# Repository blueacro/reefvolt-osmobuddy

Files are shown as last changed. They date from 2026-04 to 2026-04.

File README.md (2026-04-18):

# OsmoBuddy

OsmoBuddy is an open-source RO/DI (Reverse Osmosis / Deionization) monitor and controller for reef aquariums. It is built around an ESP32 and [ESPHome](https://esphome.io/), and feeds into [Home Assistant](https://www.home-assistant.io/) for dashboards, automations, and alerting.

For the full design story — including installation photos, parts sources, and discussion with other reefers — see the Reef2Reef thread:

**[osmoBuddy: RO/DI monitor and controller (reef2reef.com)](https://www.reef2reef.com/threads/osmobuddy-ro-di-monitor-and-controller.1078681/)**

## What it does

OsmoBuddy **monitors**:

- **Flow rate** from an inline impeller flow sensor (post-filter in the reference install)
- **Up to three pressures** from 0–5 V pressure transducers. In the reference install:
  - pre-filter (before the sediment / carbon blocks)
  - post-filter (membrane inlet)
  - RO storage tank line pressure
  — the display shows the pressure drop across the filter blocks, so it's obvious when they clog.
- **Up to three switches** (e.g. float switches on a salt-mix / ATO reservoir)

And **controls**:

- **Up to four 24 V valves or relays.** In the reference install these drive:
  - the **main water inlet valve** (a direct-acting non-diaphragm solenoid — this is the one that must not fail, so a reliable valve is used here)
  - a **flush valve** bridged across the flow restrictor to flush the RO membrane
  - (spare) a salt-mix reservoir refill solenoid
- **One on-board dry-contact relay** for signaling other controllers — for example, an **Apex** switch input used to gate automatic water change pumps (e.g. preventing AWC pumps from running after a salt-mix refill until salt has been added manually).

### Control logic

The stock firmware implements automatic pressure-based water production:

1. When storage-tank pressure drops below the **Turn On Pressure** setpoint, both the inlet and flush valves open — a **pre-flush** at startup.
2. After ~30 s the flush valve closes and the membrane starts producing water into the tank.
3. When tank pressure reaches the **Turn Off Pressure** setpoint, the flush valve re-opens for a **post-flush**.
4. After ~30 s the inlet valve closes; the flush valve stays open for a few more seconds to bleed off pressure, then closes.

It also supports a salt-mix auto-fill with a high-float safety cutoff, and a latching dry-contact signal out to an external controller.

> TDS measurement is **not** on this revision — it's planned for a future spin.

## Features

- ESP32-C3 Wi-Fi MCU running ESPHome
- ADS1115 16-bit ADC — 3 channels for 0–5 V pressure transducers
- Pulse-counter flow totalizer with persistent state across reboots
- PCA9554 I/O expander driving solenoid / relay outputs through a high-side driver
- On-board signal relay for dry-contact output to Apex or similar
- 1.3" SH1106 128×64 OLED for live local status (pressures, state, totalizer)
- Rotary encoder with push-button for local UI
- CAN transceiver (TCAN1044) for future expansion
- USB-C for flashing / debug
- 12 V DC input with on-board 5 V and 3.3 V rails

## Reference parts

| Part | Source |
|---|---|
| 24 V flush valve | AliExpress |
| 24 V main inlet valve | McMaster-Carr [5489T413](https://www.mcmaster.com/5489T413/) |
| Pressure transducers | 1/8" NPT, 100 PSI, 0–5 V, stainless — Amazon |
| Flow sensor | Inline impeller type — Amazon |

## Repository layout

| Path | Contents |
|---|---|
| `osmobuddy.yaml` | ESPHome firmware configuration |
| `osmobuddy-schematics.pdf` | Rendered schematic |
| `gerber/osmobuddy_v1/` | Gerber files for PCB fabrication |
| `bom/` | Bill of Materials (CSV) |
| `pnp/` | Pick-and-place files for assembly |
| `3d/` | Enclosure, wall mount, knob, and pump-switch add-on (Inventor, STL, 3MF) |
| `LICENSE` | Apache License 2.0 |

## Firmware

The firmware is a single ESPHome configuration (`osmobuddy.yaml`). To flash:

1. Install [ESPHome](https://esphome.io/).
2. Create a `secrets.yaml` alongside `osmobuddy.yaml` with your Wi-Fi credentials:
   ```yaml
   wifi_ssid: "your-ssid"
   wifi_password: "your-password"
   ```
3. Compile and upload:
   ```bash
   esphome run osmobuddy.yaml
   ```

Once connected, OsmoBuddy appears in Home Assistant via the ESPHome integration and exposes all sensors, switches, and the `Turn On Pressure` / `Turn Off Pressure` / `Force Off` controls.

## Manufacturing

The `gerber/`, `bom/`, and `pnp/` directories contain what's needed to order assembled boards from JLCPCB, PCBWay, or similar. The enclosure in `3d/` is designed for FDM 3D printing.

## License

Licensed under the Apache License, Version 2.0. See [LICENSE](LICENSE) for details.

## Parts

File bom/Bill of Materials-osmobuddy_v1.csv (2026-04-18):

Comment | Description | Designator | Footprint | LibRef | Quantity
CAP 4.7uF 0603 6.3V X7R | Cap Ceramic 4.7uF 6.3V X7R 10% SMD 0603 125°C Paper T/R | C300, C600, C601, C602 | FP-CL10-IPC_C | CMP-001-00101-4 | 4
CAP 0.1uF 50V X7R 0603 | Cap Ceramic 0.1uF 50V X7R 20% SMD 0603 125C Paper T/R | C301, C400, C401, C405, C407, C605, C900, C901, C902, C920, C921, C924 | FP-CL10-IPC_B | CMP-001-00084-7 | 12
CAP 4.7uF 50V X7R 1210 | CAP CER 4.7UF 50V X7R 1210 | C402, C606, C614 | CAPC3225X20N | CMP-001-00083-3 | 3
CAP 1uF 10V X7R 0603 | Cap Ceramic 1uF 10V X7R 10% SMD 0603 125C Paper T/R | C403, C406, C922, C923, C925 | FP-CL10-IPC_B | CMP-001-00085-7 | 5
CAP 56uF 63V Poly 10mm | Cap Aluminum 56uF 63V 20% (10 X 10.2mm) SMD 0.03 Ohm 1800mA 5000h 105 C Embossed T/R | C500 | FP-FKG-MFG | CMP-001-00124-1 | 1
CAP 10uF 1210 63V X7R | Multilayer Ceramic Capacitors MLCC - SMD/SMT 1210 10uF 63volts *Derate Voltage/Temp | C610 | FP-GRM32E-0_2-0_3-MFG | CMP-001-00119-1 | 1
C0603C560J5GACTU | Multilayer Ceramic Capacitor, 56 pF, 50 V, ± 5%, C0G (NP0), 0603 [1608 Metric] | C611 | FP-C0603C-CF-IPC_B | CMP-001-00126-1 | 1
CAP 0.47uF 1210 50V X7R | Multilayer Ceramic Capacitor, 0.47 uF, 50 V, ± 10%, X7R, 1210 [3225 Metric] | C612 | CAPC1210(3225)230_M | CMP-001-00128-1 | 1
CAP 22uF 25V 1210 X7R | 1210 22 uF 25 V ±20% Tolerance X7R Multilayer Ceramic Chip Capacitor | C613 | FP-1210-L_3_2_0_3-W_2_5_0-MFG | CMP-001-00125-1 | 1
SS14 |  | D500, D501, D600, D601 | SMA | CMP-080-0002-2 | 4
USBLC6-4SC6 | ESD Suppressor 15KV 6-Pin SOT-23 T/R - Product that comes on tape, but is not reeled | D700, D900 | FP-SOT23-6L-MFG | CMP-004-00040-1 | 2
OLED_1_3_CARRIERBOARD | Use 4 pin header 0901471104 on board | DISP200 | OLED_1_3_CARRIERBOARD-Footprint-1 | CMP-00028-00008-2 | 1
M50-3630342R | 3 Pos. Male SIL Vertical SMT Conn. RoHS Compliant: Yes | J400 | FP-M50-3630342R-MFG | CMP-002-00105-2 | 1
PJ-0XX | 2.0 x 6.5 mm, 2.5 A, Horizontal, Through Hole, Dc Power Jack Connector | J500 | CUI-PJ-002A_V | CMP-167-0003-2 | 1
43045-0601 | Connector Wire to Board Header 6 Position 3 mm Solder Right Angle Thru-Hole Micro-Fit 3.0™ | J501, J502 | FP-43045-0601-MFG | CMP-002-00095-1 | 2
10155435-00011LF | 16 Position 5 A USB Right Angle Receptacle Connector | J700 | AMPHENOL_10155435-00011LF | CMP-243-000000-3 | 1
1803277 | Pluggable Header 3.81mm 16AWG 160V 8A 2 Position COMBICON MC Series | J800, J801, J802, J803, J900, J901, J902 | PHOENIX_1803277 | CMP-249-000000-3 | 7
1803280 |  | J804, J920, J921, J922, J923 | PHOENIX_1803280 | CMP-251-000000-3 | 5
G6S-2-Y-DC12 | Electromechanical Relay 12VDC 720Ohm 2A DPDT (14.8x7.3x9.2)mm THT Signal Relay | K800 | FP-G6S-2-Y-DC12-MFG | CMP-008-00007-1 | 1
SRN4018-4R7M | Ind Power Semi-Shielded Wirewound 4.7uH 20% 100KHz Ferrite 1.9A 1515 T/R | L600 | FP-SRN4018-MFG | CMP-006-00036-2 | 1
LED_INDICATOR |  | LED400, LED401 | LED5MM | CMP-130-0003-6 | 2
NFET |  | Q400, Q401 | SOT23-3 | CMP-094-0000-1 | 2
10K 0603 1% | Res General Purpose Thick Film 0603 10K Ohm 1% 1/10W ±100ppm/°C Molded SMD Paper T/R | R400, R401, R402, R404, R405, R408, R409, R410, R900, R902, R904, R922 | RESC1608-IPC-ML | CMP-009-00191-4 | 12
120R 1210 5% | SMD Chip Resistor, 120 Ohm, ± 5%, 500 mW, 1210 [3225 Metric], Thick Film, General Purpose | R403 | RESC3225X70X50LL20T20 | CMP-009-00240-1 | 1
220R 0603 5% | YAGEO - RC0603JR-07220RL - SMD Chip Resistor, 0603 [1608 Metric], 220 ohm, RC Series, 75 V, Thick Film, 100 mW | R406, R407 | RESC1608-IPC-ML | CMP-009-00183-3 | 2
100k 0603 1% | Res Thick Film 1.6 x 0.8 mm 100K Ohm 1% 0.1W(1/10W) 100ppm/ C Molded SMD Paper T/R | R600 | RESC1608-IPC-LL | CMP-009-00203-1 | 1
22.1k 0603 0.1% | RES SMD 22.1KOHM 0.1% 1/10W 0603 | R601 | RESC1608-IPC-LL | CMP-009-00207-3 | 1
AC0402FR-075K1L | SMD Chip Resistor, 5.1 kOhm, ± 1%, 63 mW, 0402 [1005 Metric], Thick Film, General Purpose | R700, R701 | FP-AC0402-IPC_A | CMP-009-00234-1 | 2
1K 0603 1% | Res Thick Film 0603 1K Ohm 1% 1/10W ±100ppm/°C Molded SMD Punched Carrier T/R | R901, R903, R905, R920, R921, R923, R924, R925, R926, R927 | RESC1608-IPC-ML | CMP-009-00193-3 | 10
PTS526SK15SMTR2LFS | Switch Tactile N.O. SPST Round Button Gull Wing 0.05A 12VDC 200000Cycles 2.45N SMD T/R | RST400 | FP-PTS526SK15SMTR2LFS-MFG | CMP-011-00015-1 | 1
RENC_SW |  | SW400 | EN11-HSB | CMP-066-0000-1 | 1
ADS1115IDGSR | 4-Channel Single ADC Delta-Sigma 860sps 16-bit Serial 10-Pin VSSOP T/R | U300 | FP-DGS0010A-MFG | CMP-015-00014-1 | 1
ESP32-C3-MINI-1-N4 | Bluetooth, WiFi 802.11b/g/n, Bluetooth v5.0 Transceiver Module 2.412GHz ~ 2.484GHz PCB Trace Surface Mount | U400 | XCVR_ESP32-C3-MINI-1-N4 | CMP-206-000000-1 | 1
TCAN1044VDRQ1 | R-PDSO-G8 TCAN1044 Tape & Reel (TR) CAN interface transceiver 100mV 4.905mm 5Mbps -40C~125C TA | U401 | FP-D0008A-IPC_B | CMP-015-00017-1 | 1
PCA9554APW | I2C/SMBus Interface 100kHz/400kHz 5.5V 16-Pin TSSOP Tube / IC I/O EXPANDER I2C 8B 16TSSOP | U402 | PW0016A_L | CMP-015-00016-1 | 1
TPS70950DBVT | IC REG LINEAR 5V 150MA SOT23-5 / 150-mA, 30-V, UltraLow IQ, Low-Dropout Regulators with Enable | U600, U601 | FP-DBV0005A-IPC_B | CMP-019-00083-1 | 2
TPS54202DDCR | 4.5V to 28V Input, 2A Output, EMI Friendly Synchronous Step-Down Converter 6-SOT-23-THIN -40 to 125 | U602 | FP-DDC0006A-IPC_C | CMP-019-00081-1 | 1
TBD62783AFG | Power Switch Hi Side 4A 18-Pin SOP | U800 | SOIC127P1030X245-18N | CMP-024-00012-1 | 1

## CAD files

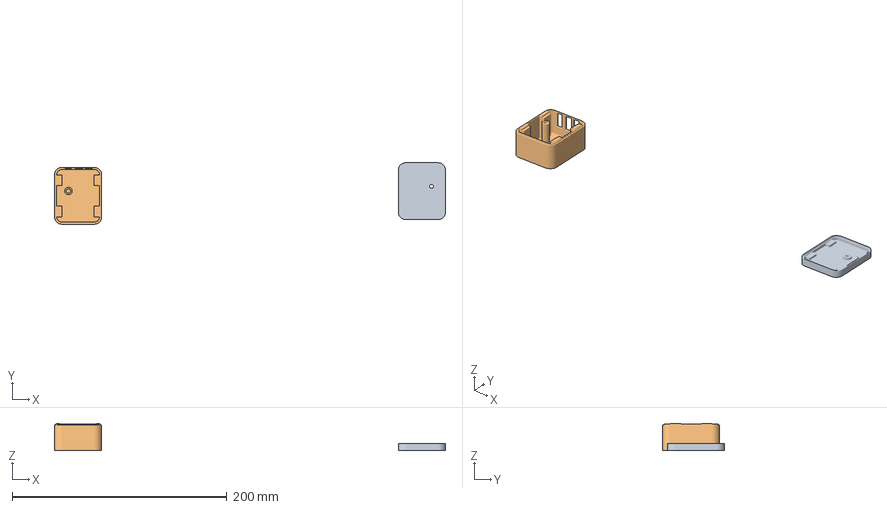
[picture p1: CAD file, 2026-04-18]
3d/pumpswitch_bottom.3mf
364.2 x 57.3 x 25.5 mm
pumpswitch_bottom.stl
pumpswitch_top.stl

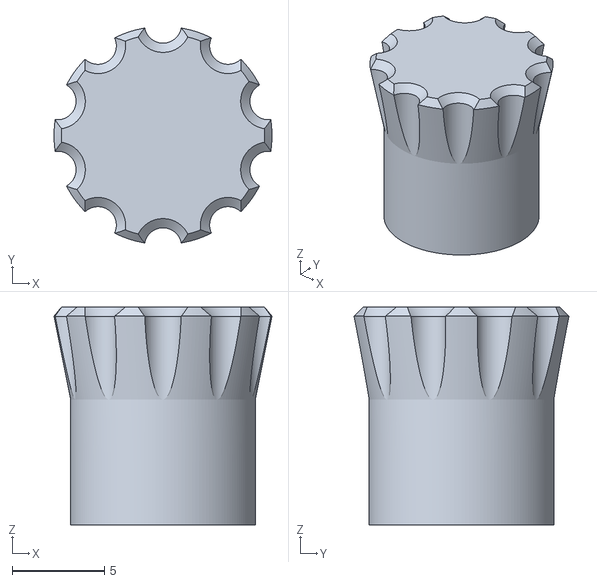
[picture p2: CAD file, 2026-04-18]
3d/Knob.stl
11.8 x 11.6 x 11.8

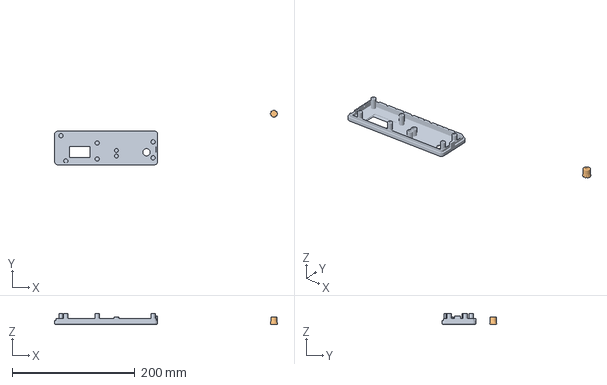
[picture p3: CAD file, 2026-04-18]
3d/osmobuddy_top.3mf
362.7 x 88.9 x 17.2 mm
osmobuddy_top.stl
Knob.stl

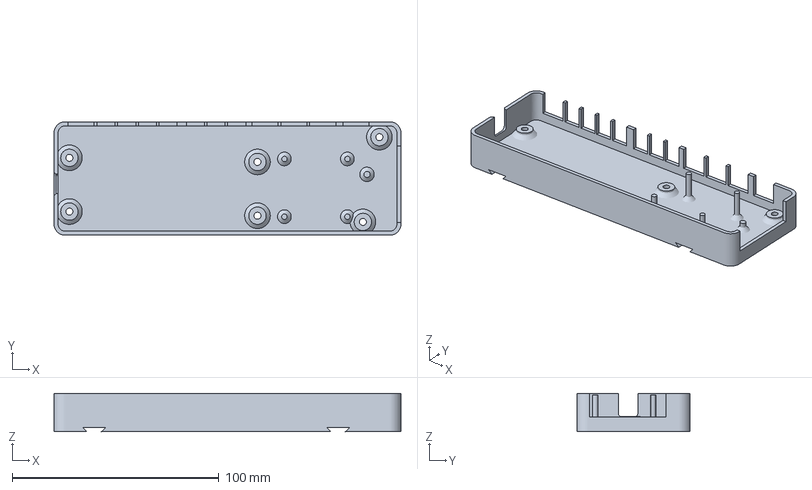
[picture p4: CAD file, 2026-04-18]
3d/osmobuddy_bottom.3mf
167.9 x 54.9 x 18.6 mm

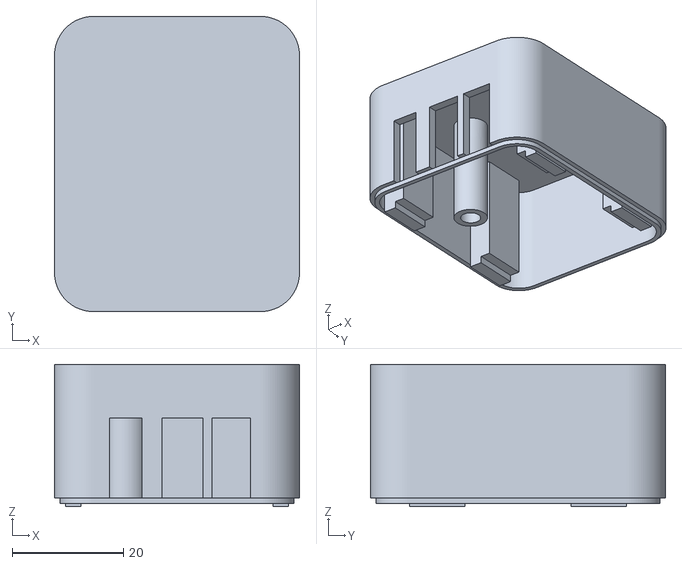
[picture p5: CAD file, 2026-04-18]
3d/pumpswitch_top.stl
44.0 x 53.0 x 25.5

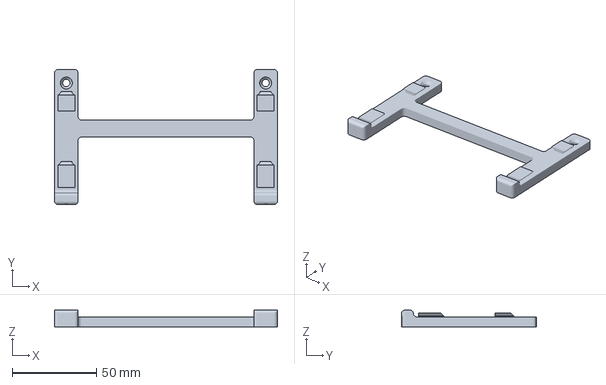
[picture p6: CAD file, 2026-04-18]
3d/_Wallmount.3mf
132.0 x 79.9 x 10.0 mm

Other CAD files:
3d/Knob.ipt
3d/PCB/ConvertedComponents/AMPHENOL_10155435-00011LF_CMP-243-000000-3.ipt
3d/PCB/ConvertedComponents/CAPC1210(3225)230_M_CMP-001-00128-1.ipt
3d/PCB/ConvertedComponents/CAPC3225X20N_CMP-001-00083-3.ipt
3d/PCB/ConvertedComponents/CUI-PJ-002A_V_CMP-167-0003-2.ipt
3d/PCB/ConvertedComponents/EN11-HSB_CMP-066-0000-1.ipt
3d/PCB/ConvertedComponents/FP-1210-L_3_2_0_3-W_2_5_0-MFG_CMP-001-00125-1.ipt
3d/PCB/ConvertedComponents/FP-43045-0601-MFG_CMP-002-00095-1.ipt
3d/PCB/ConvertedComponents/FP-AC0402-IPC_A_CMP-009-00234-1.ipt
3d/PCB/ConvertedComponents/FP-C0603C-CF-IPC_B_CMP-001-00126-1.ipt
3d/PCB/ConvertedComponents/FP-CL10-IPC_B_CMP-001-00084-7.ipt
3d/PCB/ConvertedComponents/FP-CL10-IPC_B_CMP-001-00085-7.ipt
3d/PCB/ConvertedComponents/FP-CL10-IPC_C_CMP-001-00101-4.ipt
3d/PCB/ConvertedComponents/FP-D0008A-IPC_B_CMP-015-00017-1.ipt
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

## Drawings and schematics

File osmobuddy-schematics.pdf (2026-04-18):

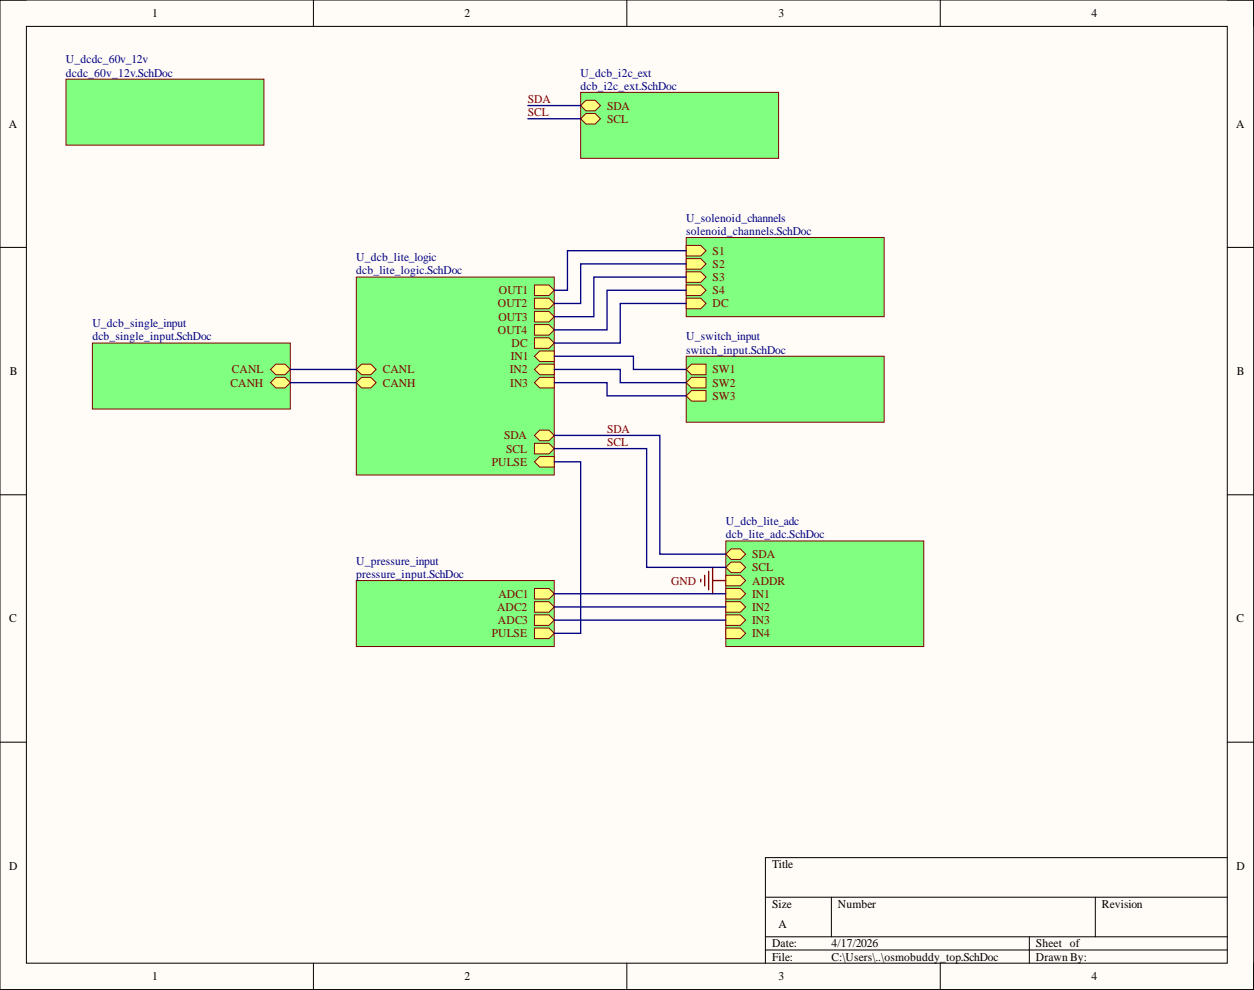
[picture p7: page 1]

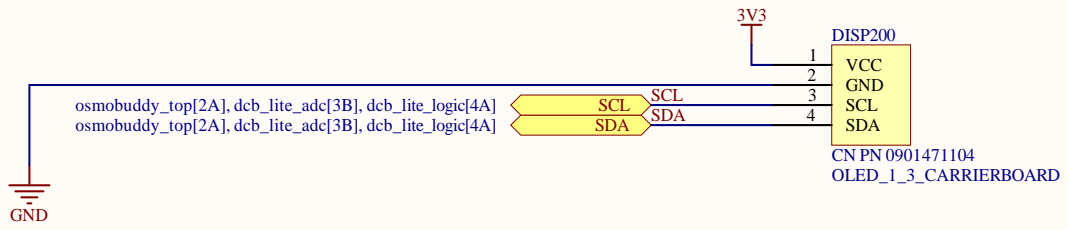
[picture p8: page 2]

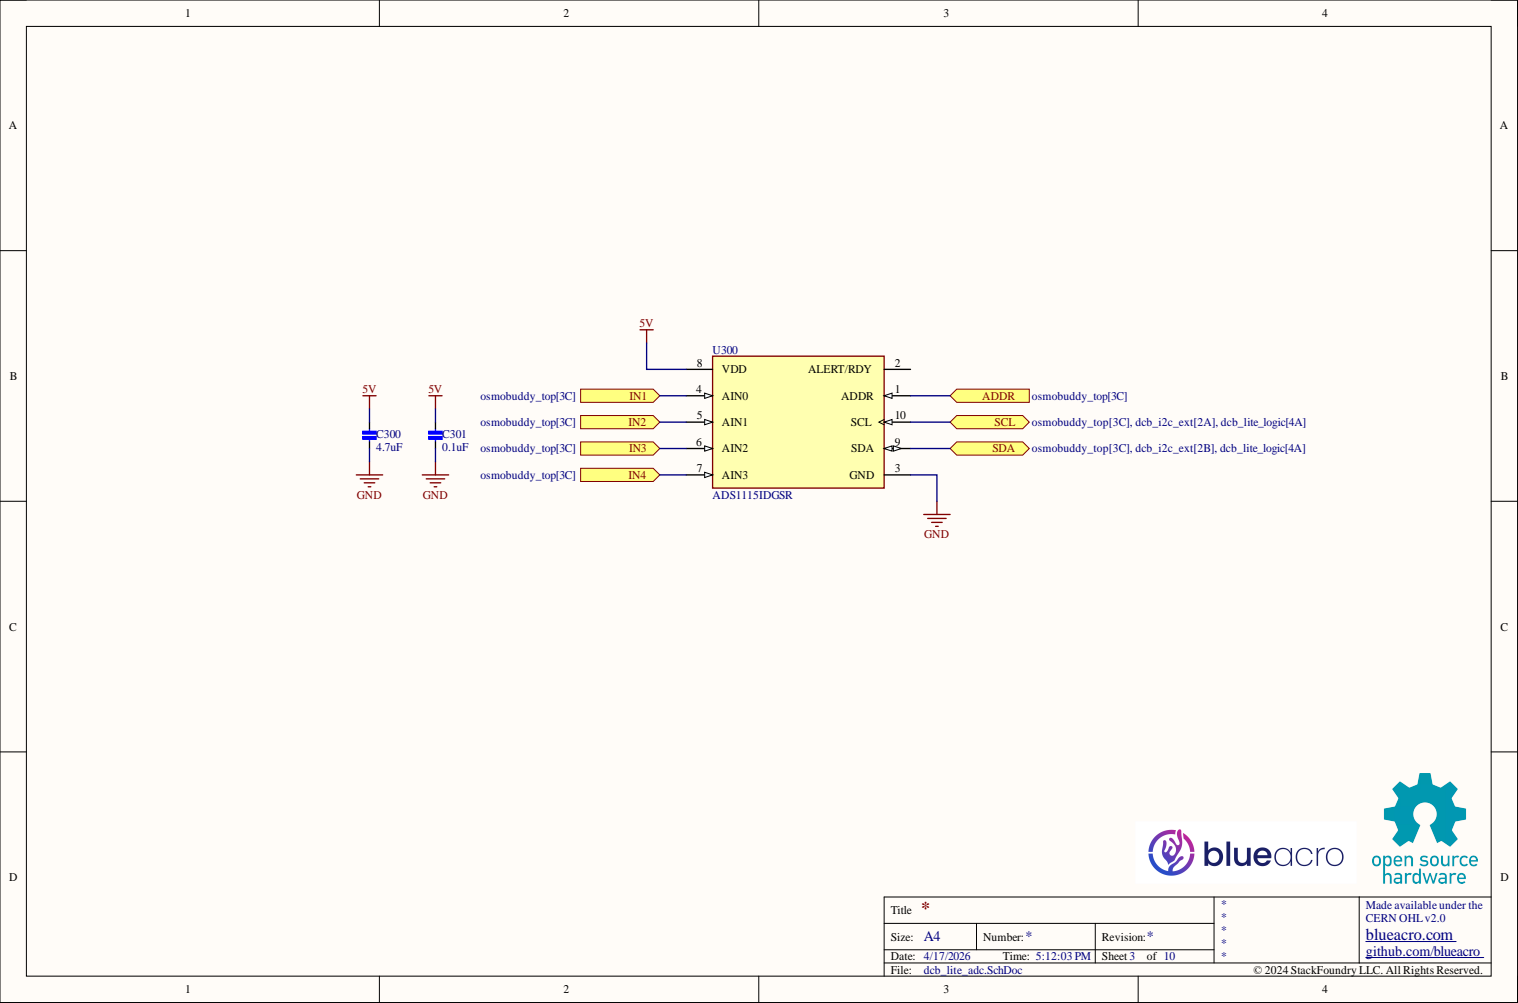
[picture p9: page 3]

Made available under the
CERN OHLv2.0
blueacro.com
github.com/blueacro

© 2024 StackFoundry LLC. All Rights Reserved.

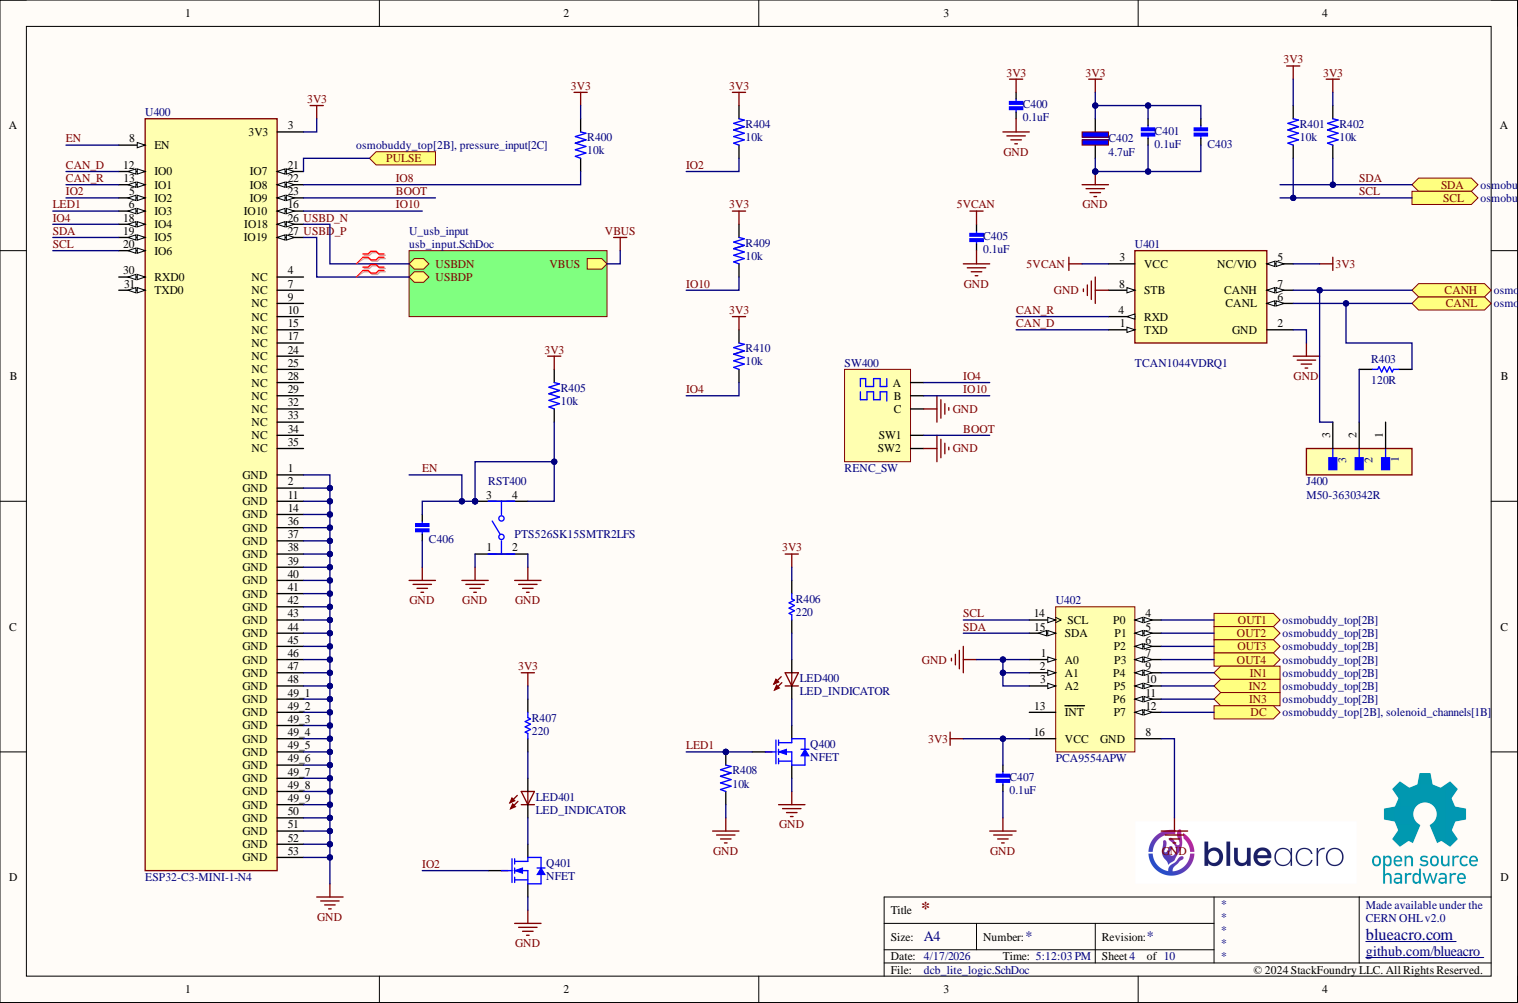
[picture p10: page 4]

2 7 | USBD _P

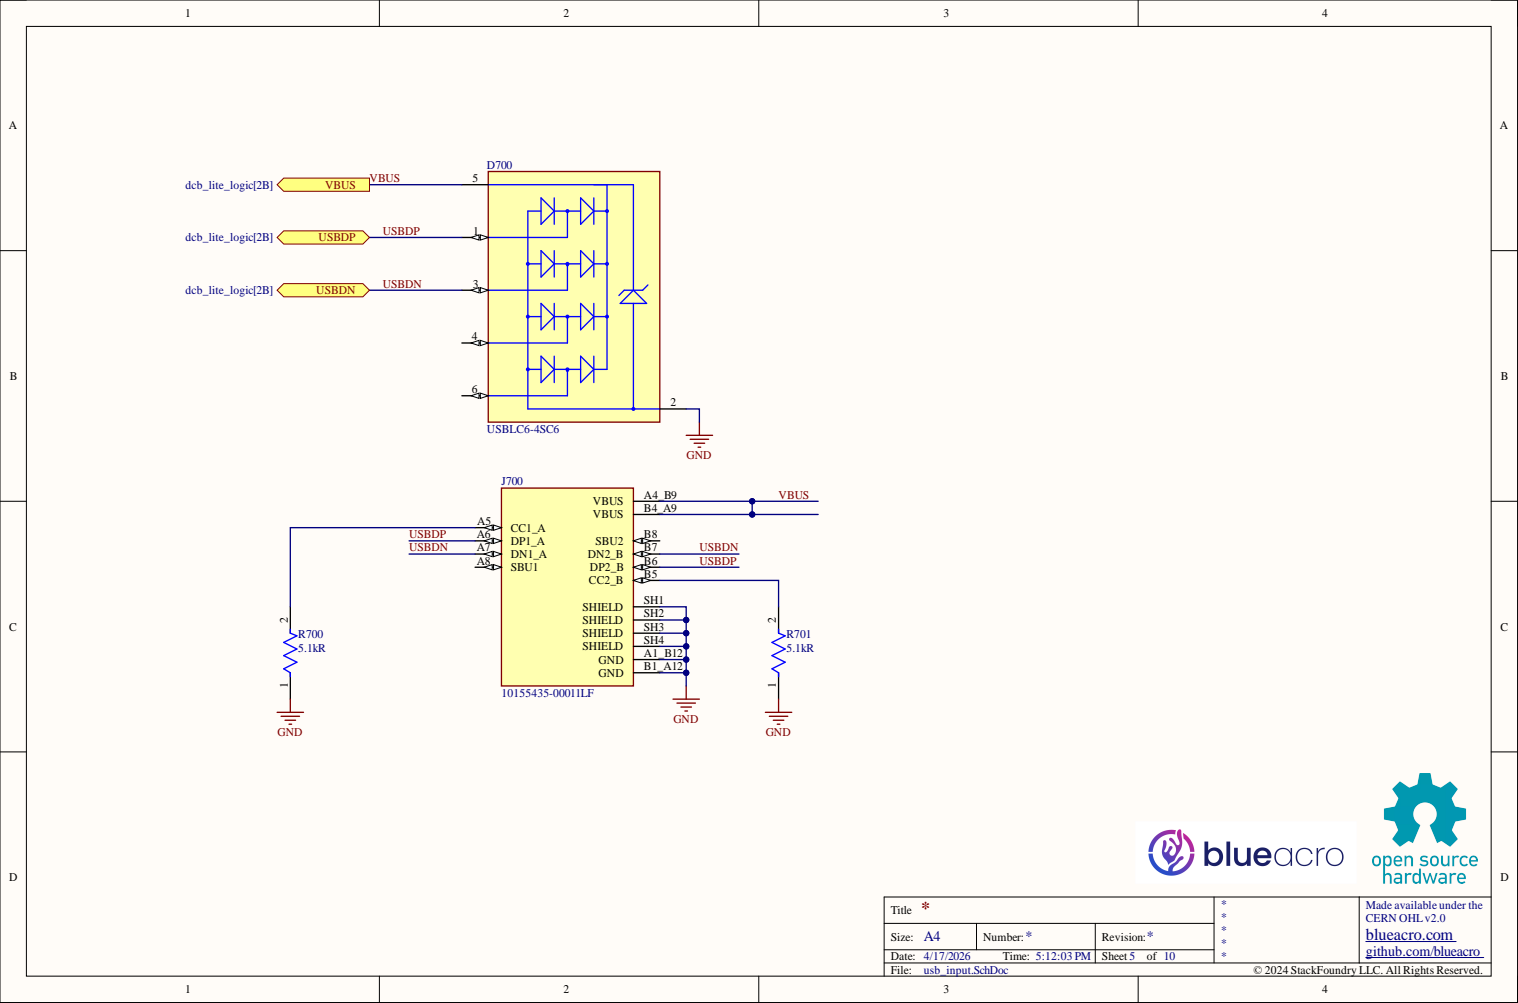
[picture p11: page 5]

Made available under the

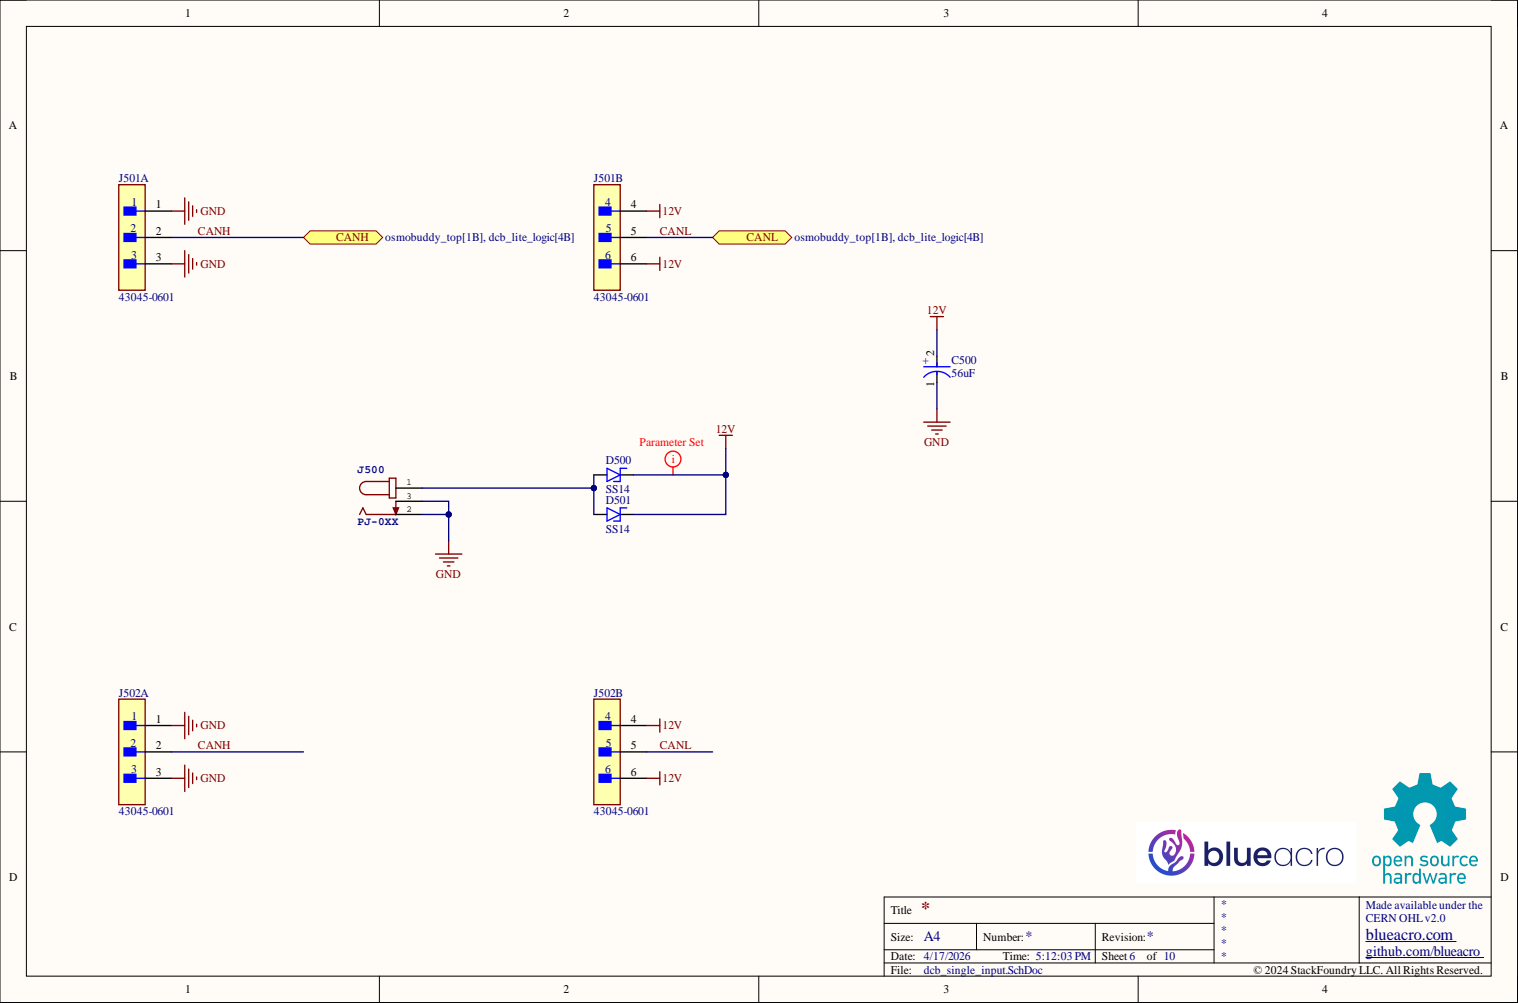
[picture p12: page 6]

Made available under the

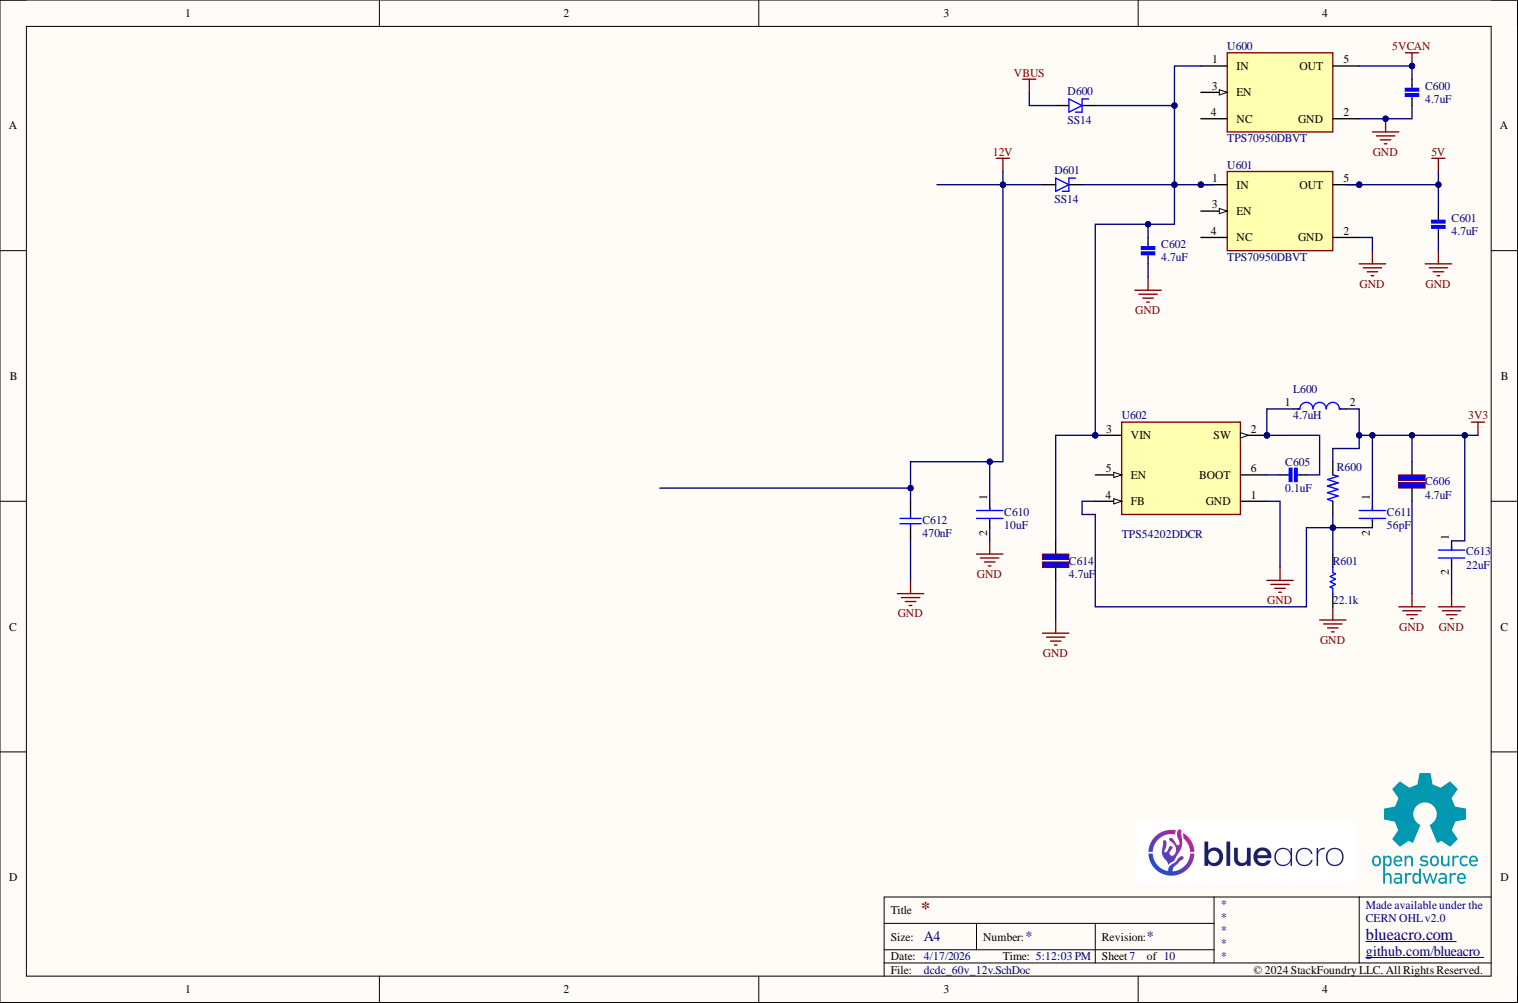
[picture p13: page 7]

Made available under the

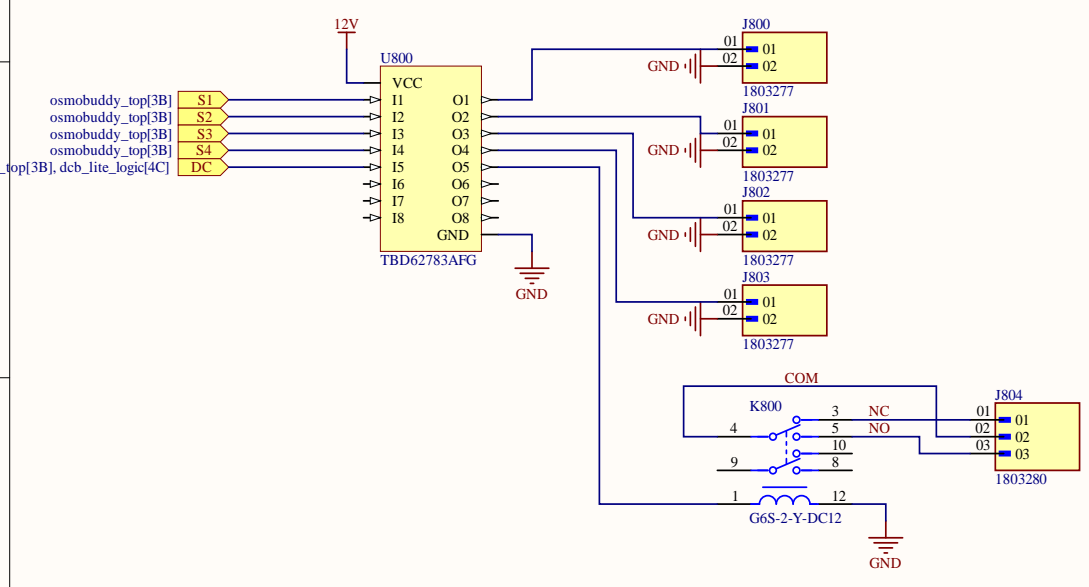
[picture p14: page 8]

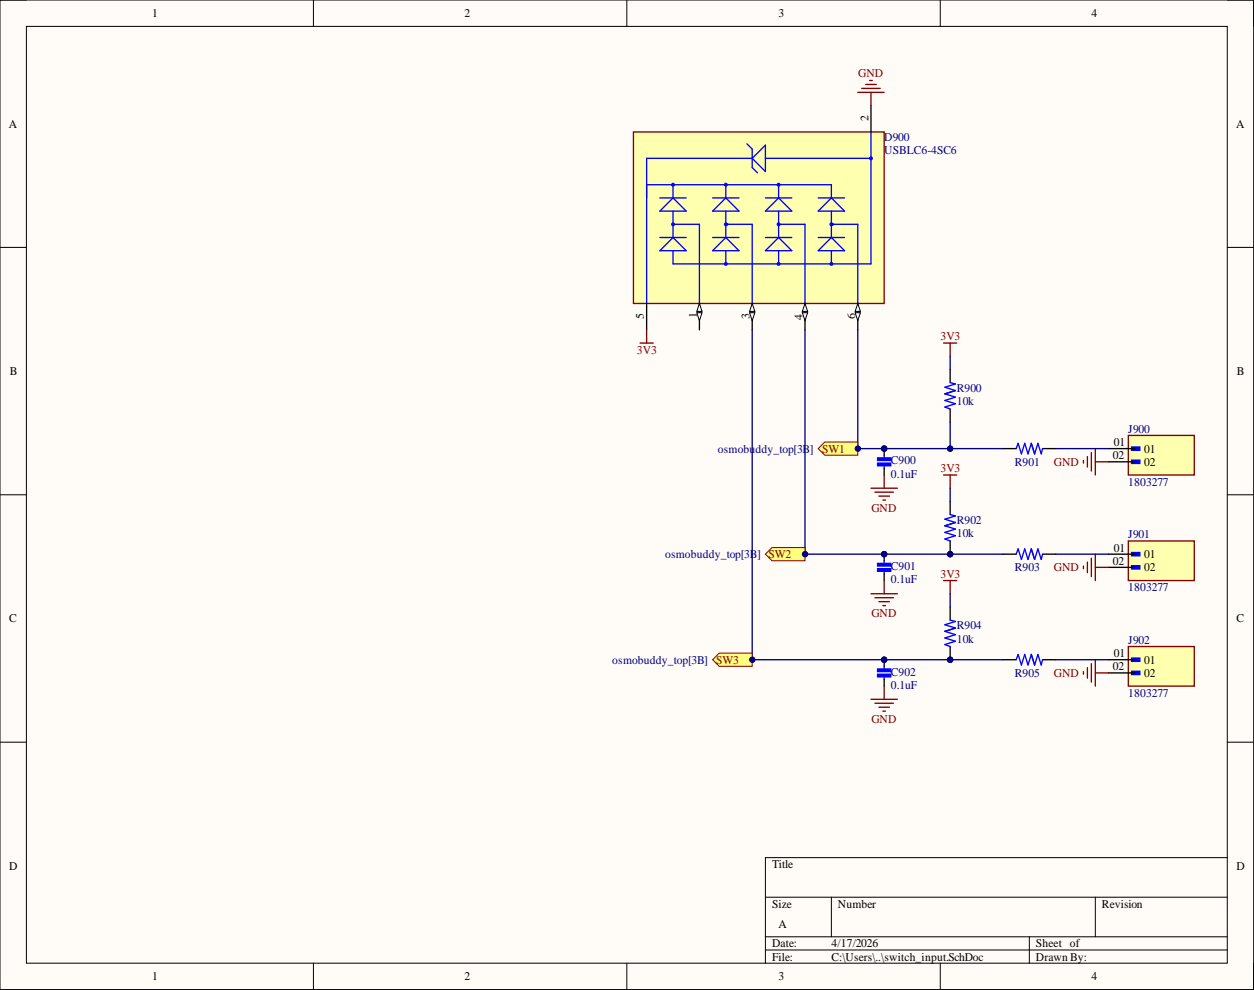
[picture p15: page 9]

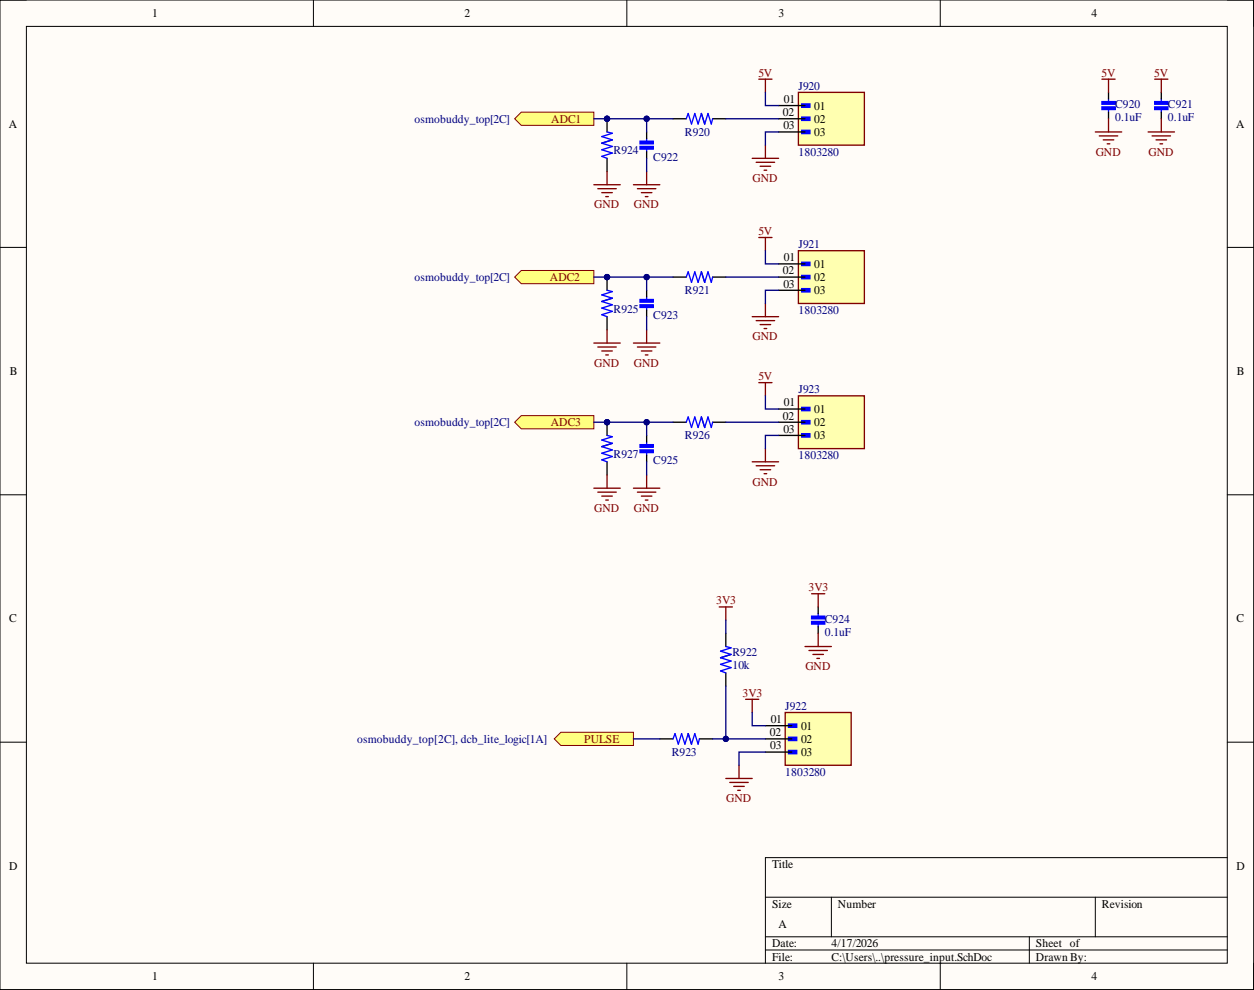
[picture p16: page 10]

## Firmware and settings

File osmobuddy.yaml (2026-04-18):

esphome:
  name: osmobuddy-test
  friendly_name: osmobuddy-test
  project:
    name: reefvolt.osmobuddy
    version: "GIT_VERSION_FIELD"

esp32:
  board: esp32-c3-devkitm-1
  framework:
    type: arduino

# Enable logging
logger:

# Enable Home Assistant API
api:

ota:
  - platform: esphome
wifi:
  ssid: !secret wifi_ssid
  password: !secret wifi_password

  # Enable fallback hotspot (captive portal) in case wifi connection fails
  ap:
    ssid: "Osmobuddy-Test Fallback Hotspot"
    password: "testtest"

captive_portal:
    

font:
    - file: 'five.ttf'
      id: five
      size: 8
    - file: "refsan.ttf"
      id: refsan
      size: 9
    - file: "PixelGameFont.ttf"
      id: bigfont
      size: 20

interval:
  - interval: 5s
    then:
      - script.execute: update_salt_fill
  - interval: 0.5s
    then:
      - if:
          condition:
            switch.is_on: port_water_inlet
          then:
            - output.turn_on: led2
          else:
            - output.turn_off: led2

status_led:
  pin: 
    number: GPIO2
    inverted: true

output:
  - platform: gpio
    id: led2
    pin: GPIO3


display:
  - platform: ssd1306_i2c
    model: "SH1106 128x64"
    #address: 0x78
    update_interval: 1s
    lambda: |-
      int offset = 0;
      it.printf(0, 3+offset, id(five), "Tank");
      it.printf(38, offset, id(bigfont), "%2.0f", fabs(id(psi_a).state));
      offset += 24;
      it.printf(0, 3+offset, id(five), "Filter");
      it.printf(38, offset, id(bigfont), "%2.0f (%1.1f)", fabs(id(psi_b).state), fabs(id(psi_c).state - fabs(id(psi_b).state)));
      offset += 24;
      if (id(port_water_inlet).state == true) {
        it.printf(3, offset, id(bigfont), "ON");
      }
      if (id(port_flush).state == true) {
        it.printf(33, offset, id(bigfont), "FL");
      }
      if (id(port_salt_fill).state == true) {
        it.print(63, offset, id(bigfont), "SF");
      }

      it.printf(80, offset, id(five), "T:%.0f", id(flow_integ).state/1000.0);
      it.set_rotation(DISPLAY_ROTATION_270_DEGREES);
      it.printf(48, 115, id(five), "PSI");
      it.printf(48-24, 115, id(five), "PSI");
      it.set_rotation(DISPLAY_ROTATION_0_DEGREES);

script:
  - id: update_salt_fill
    mode: restart
    then:
      - if:
          condition:
            - binary_sensor.is_off: float_high # If the switch opens due to high water, make sure to turn off the fill valve
          then:
            - switch.turn_off: port_salt_fill
      - if:
          condition:
            - binary_sensor.is_on: float_low # If the switch is closed, send the signal to the Apex and latch
          then:
            - switch.turn_on: port_relay
  
  - id: stop_water_production
    mode: single
    then:
      - script.stop: start_water_production
      - switch.turn_on: port_flush
      - delay: 30s
      - switch.turn_off: port_flush # Turn off flush first to reduce flow to reduce water hammer
      - delay: 1s
      - switch.turn_off: port_water_inlet 
      - delay: 10s
      - switch.turn_on: port_flush # Drain pressure
      - delay: 5s
      - switch.turn_off: port_flush
  - id: start_water_production
    mode: single
    then:
      - script.stop: stop_water_production
      - if:
          condition:
            - switch.is_on: force_turn_off
          then:
            - script.stop: start_water_production # Stop ourselves
      - switch.turn_on: port_water_inlet
      - if: 
          condition:
            - switch.is_off: port_flush
          then:  
            - switch.turn_on: port_flush
      - delay: 30s
      - switch.turn_off: port_flush
          

  
i2c:
  sda: GPIO5
  scl: GPIO6
  scan: true
  id: bus_a
  frequency: 400kHz

ads1115:
  - address: 0x48
    id: ads1115_1
pca9554:
  - id: 'pca9554a_device'
    address: 0x38

number:
  - platform: template
    name: "Turn On Pressure"
    id: turn_on_pressure
    optimistic: true
    restore_value: True
    initial_value: 10
    min_value: 0
    max_value: 50
    step: 1
  - platform: template
    name: "Turn Off Pressure"
    id: turn_off_pressure
    optimistic: true
    restore_value: True
    initial_value: 20
    min_value: 0
    max_value: 50
    step: 1

binary_sensor:
  - platform: gpio
    id: float_low
    name: "Float Low"
    publish_initial_state: true
    filters:
      - delayed_on_off: 5s
    pin:
      pca9554: pca9554a_device
      number: 4
      mode:
        input: true
      inverted: true
  - platform: gpio
    id: float_high
    name: "Float High"
    publish_initial_state: true
    pin:
      pca9554: pca9554a_device
      number: 5
      mode:
        input: true
      inverted: true
    filters:
      - delayed_on_off: 5s
    on_state:
      - script.execute: update_salt_fill

  - platform: gpio
    id: float_c
    name: "Float C"
    publish_initial_state: true
    pin:
      pca9554: pca9554a_device
      number: 6
      mode:
        input: true
      inverted: true
    filters:
      - delayed_on_off: 5s
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

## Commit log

2026-04-18 Osmobuddy schematics
    [osmobuddy_v1.GBL, osmobuddy_v1.GBO, osmobuddy_v1.GBP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]
2026-04-18 BOM and PnP
    [Bill of Materials-osmobuddy_v1.csv, Pick Place for osmobuddy_v1.csv]
2026-04-18 3d models
    [AMPHENOL_10155435-00011LF_CMP-243-000000-3.0001.ipt, AMPHENOL_10155435-00011LF_CMP-243-000000-3.ipt, CAPC1210(3225)230_M_CMP-001-00128-1.0001.ipt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]
2026-04-18 Add GitHub Actions CI for ESPHome build and installer page (#1)
    * Add GitHub Actions CI for ESPHome build and firmware installer
    - esphome.yml validates every push/PR by compiling osmobuddy.yaml
    - publish.yml builds on release/dispatch and deploys an ESP Web Tools
    installer page to GitHub Pages (gh-pages branch)
    - Inject git describe into esphome.project.version via GIT_VERSION_FIELD
    - Bring in display fonts (five.ttf, refsan.ttf, PixelGameFont.ttf) and
    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
